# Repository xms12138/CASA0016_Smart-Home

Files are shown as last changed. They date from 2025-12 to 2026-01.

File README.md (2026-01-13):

# 🏡 HomeCare Assist  

**Smart-Home Prototype for Elderly Comfort & Safety**  

A lightweight Arduino-based system for indoor comfort monitoring and automated actuation.

---

## ✨ Overview  

**HomeCare Assist** is a room-level smart prototype designed to support **elderly individuals living alone**, helping them maintain a safer and more comfortable indoor environment—**without cameras, wearables, or user intervention**.

The system continuously monitors:

- Indoor **CO₂ / temperature / humidity**
- Indoor & outdoor **light levels**
- **Thermal-based occupancy** 
- Potential **fire hazards**

And automatically:

- Opens/closes curtains based on natural light
- Activates ventilation when air quality/temperature rises
- Triggers alarms when fire is detected
- Publishes live data via **MQTT** for remote monitoring & manual control

<p align="center">
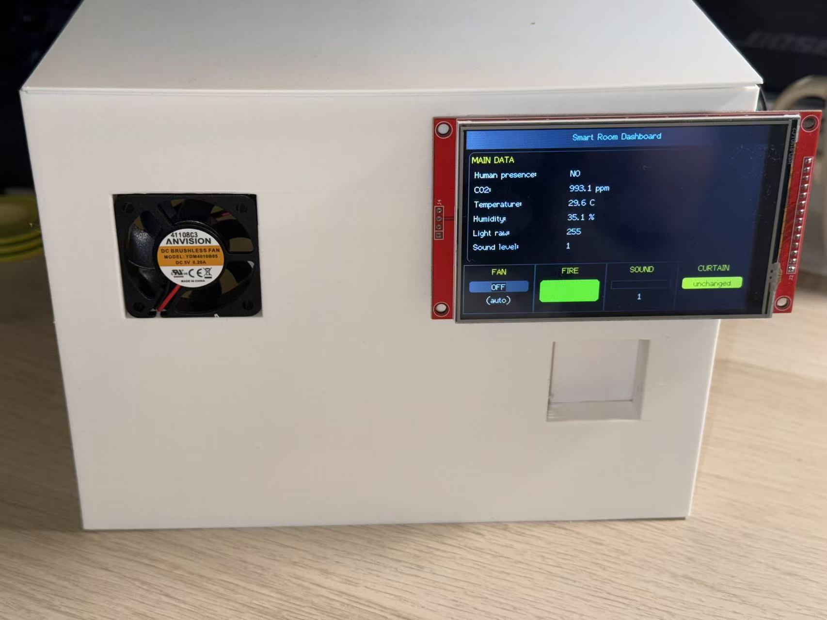
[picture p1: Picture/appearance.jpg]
  
  <br>
  <strong>Figure 1.</strong> Physical Prototype Overview
</p>

---

## 🧩 Key Features  

- ✅ Privacy-friendly **thermal presence detection** (no camera)
- ✅ Real-time **multi-sensor monitoring**
- ✅ **Automatic ventilation & curtain control**
- ✅ **MQTT remote supervision + manual override**
- ✅ Local **TFT dashboard UI**
- ✅ Low-power design (suitable for standalone power bank)

------

## 🚀 Installation & Usage

### 1️⃣ Clone

```
git clone https://github.com/xms12138/CASA0016_Smart-Home.git
```

**The complete code of this system is located in the [Final](https://github.com/xms12138/CASA0016_Smart-Home/tree/main/Code/Final). If you just want to give it a try, all you need to do is run this code.**

**Individual debugging sketches for each component are available in the [Components_Test](https://github.com/xms12138/CASA0016_Smart-Home/tree/main/Code/Components_Test) folder and can be run independently if required.**

### 2️⃣ Arduino Libraries

Install these in Arduino IDE:

- Adafruit MLX90640
- Adafruit SCD30
- TFT_eSPI
- WiFiNINA
- PubSubClient
- Servo

### 3️⃣ Configure WiFi + MQTT

Edit in your Arduino sketch:

```
char ssid[] = "YOUR_WIFI";
char pass[] = "YOUR_PASSWORD";

const char* mqttServer = "Your_Server";
const int mqttPort = "Your_Port";
```

### 4️⃣ Upload & Run

- Wire all sensors following the schematic
- Upload sketch to **Arduino MKR WiFi 1010**
- Verify TFT screen updates
- Use an MQTT client (e.g. EasyMQTT) to publish fan commands

------

## 📂 Recommended Repository Structure

```
CASA0016_Smart-Home/
│
├── 3D-Printer/    – 3D model files for the device enclosure and printed parts
│
├── Code/          – Arduino firmware and source code for sensors, actuators and MQTT
│
├── Picture/       – Photos, wiring images, UI screenshots and documentation images
│
└── website/       – Web dashboard (HTML/CSS/JS) for visualizing device data

```

Each folder corresponds to a core part of the smart home prototype:

- **3D-Printer** → physical housing & printed components
- **Code** → main hardware logic running on the microcontroller
- **Picture** → project images and build documentation
- **website** → the browser-based dashboard for monitoring

---

## 🛠 Hardware Used  

| Component | Purpose |
| --- | --- |
| Arduino MKR WiFi 1010 | Main controller, WiFi connectivity |
| MLX90640 (32×24 Thermal Camera) | Human presence detection |
| SCD30 | CO₂ + Temperature + Humidity monitoring |
| Light sensor (LDR) | Ambient light measurement |
| Flame sensor | Fire detection |
| MG90S Servo | Simulated curtain control |
| 5V Fan | Auto / remote ventilation |
| TFT_eSPI Display (480×320) | On-device dashboard UI |

---

## 🧱 System Architecture  

The system runs on an Arduino MKR WiFi 1010 and integrates five key modules:

 MLX90640 for thermal presence detection, SCD30 for CO₂/temperature/humidity, an LDR for light sensing, a flame sensor for fire detection, and actuators including a PWM-controlled fan and a servo-driven curtain. All readings are displayed locally on a TFT screen and trigger automatic responses. The circuit diagram is as follows:

<p align="center">
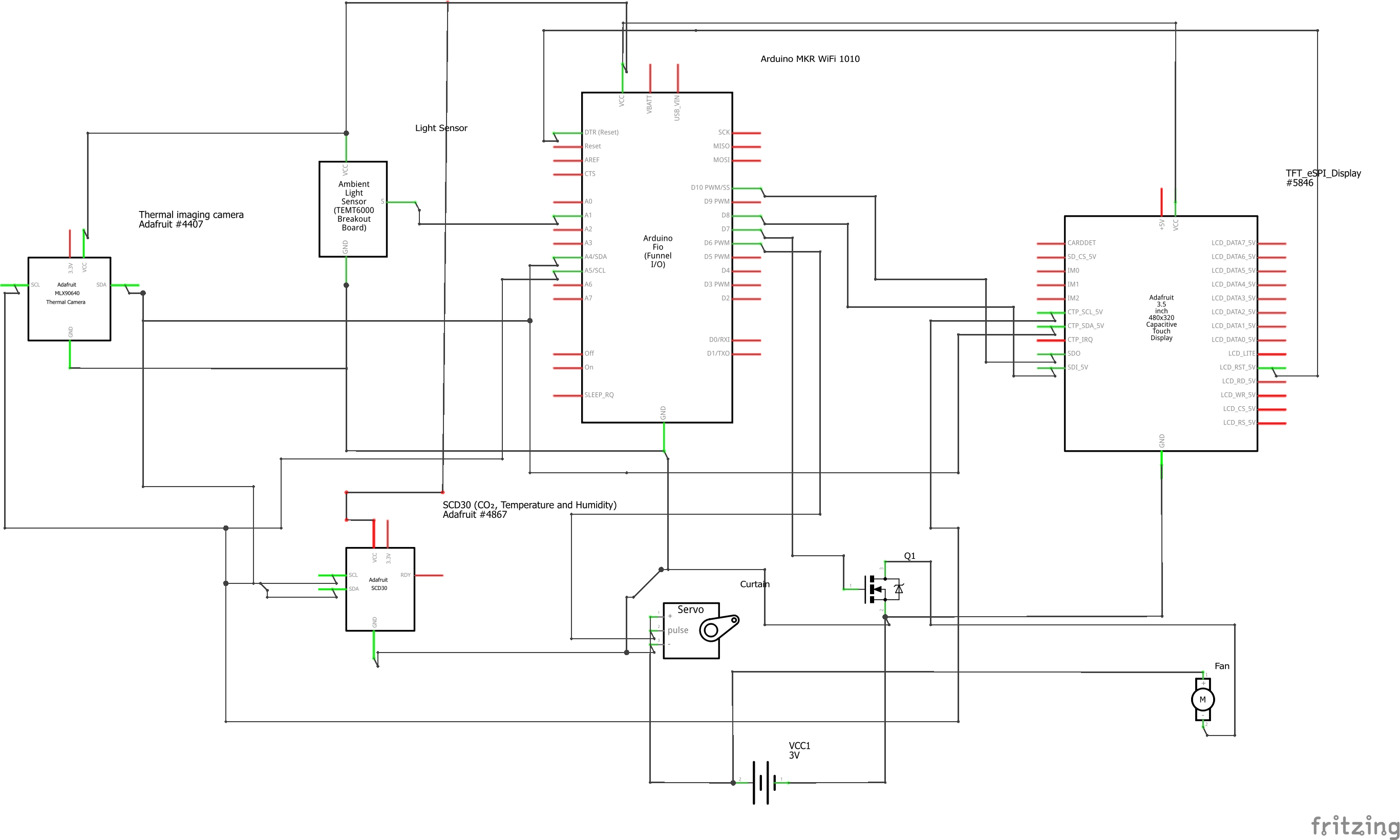
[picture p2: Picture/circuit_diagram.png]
  
  <br>
  <strong>Figure 2.</strong> Circuit Diagram
</p>

The component diagram is as follows:

<p align="center">
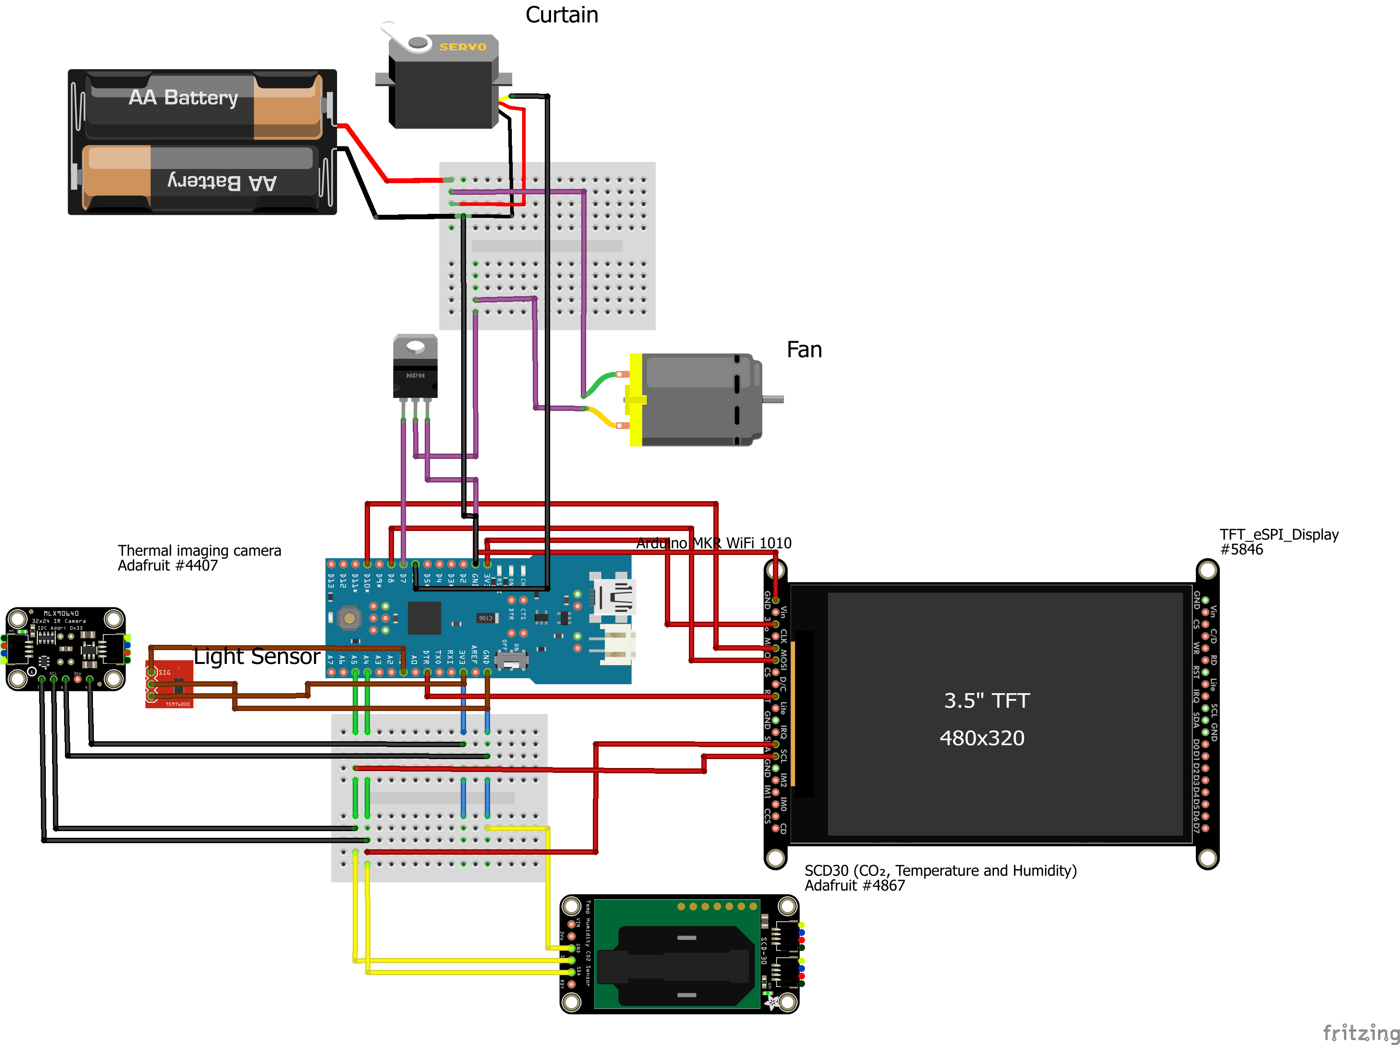
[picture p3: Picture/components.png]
  
  <br>
  <strong>Figure 3.</strong> Components Diagram
</p>

------

## 🧪 Software Logic and Core Function

The system first determines occupancy using the thermal imager. If empty, all actuators stay idle. When occupied, rule-based thresholds control devices: CO₂ and temperature trigger the fan, light opens the curtains, and a flame event raises an alarm. This ensures predictable behaviour across all sensors. The workflow diagram is as follows:

<p align="center">
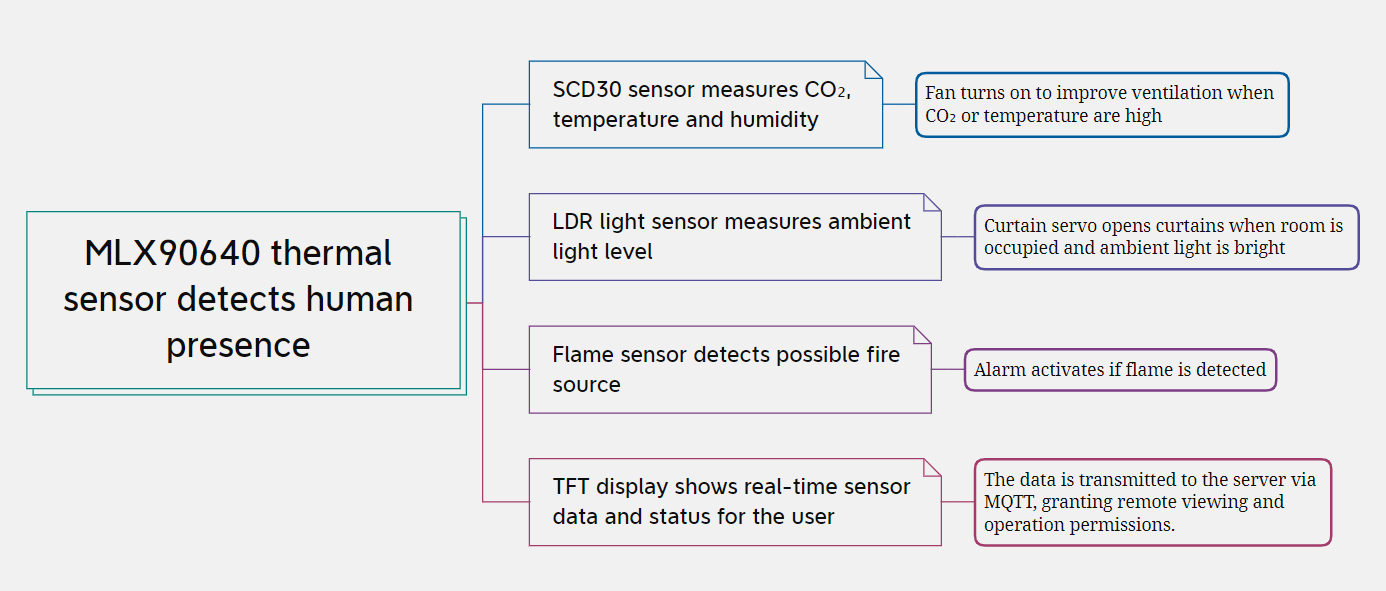
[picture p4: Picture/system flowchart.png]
  
  <br>
  <strong>Figure 4.</strong> System Flowchart
</p>

### 🔥 Thermal Presence Detection (MLX90640)

Presence is inferred using an adaptive, statistics-based method rather than fixed thresholds:

- Compute global mean **μ** and standard deviation **σ** per 32×24 frame
- Mark “hot” pixels by **z-score thresholding**
- Aggregate into **8×6 blocks** to suppress isolated noise
- Require global contrast check (**Tmax − μ**)
- Apply **temporal smoothing** to stabilize decisions

<p align="center">
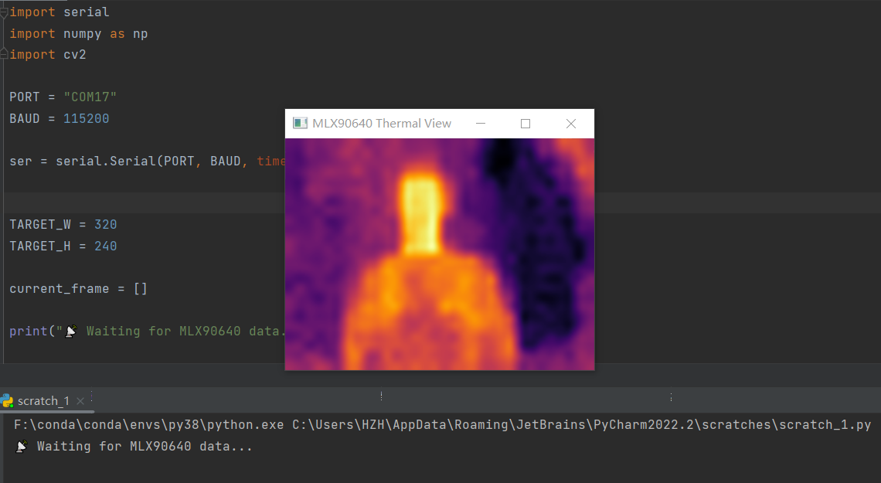
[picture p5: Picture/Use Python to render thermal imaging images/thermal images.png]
  
  <br>
  <strong>Figure 5.</strong> Use Python to render thermal imaging images
</p>

------

### 🌬 Automatic & Remote Fan Control

Automatic mode runs only when presence is detected:

- Fan ON if **CO₂ > 5000 ppm** OR **Temperature > 29°C**
- MQTT remote control can force ON/OFF using:
  - Topic: `student/MUJI/HZH/command/fan`
  - Payload: `"on"` / `"off"`

<p align="center">
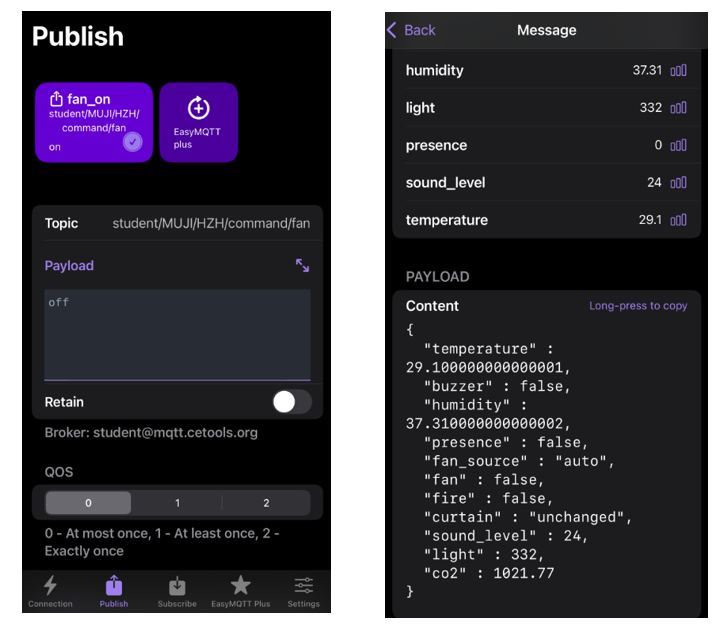
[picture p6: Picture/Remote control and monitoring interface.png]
  
  <br>
  <strong>Figure 6.</strong> Remote control and monitoring interface
</p>

Example JSON payload (remote monitoring):

```
{
  "temperature": 29.1,
  "humidity": 37.3,
  "presence": false,
  "fan_source": "auto",
  "fan": false,
  "fire": false,
  "curtain": "unchanged",
  "light": 332,
  "co2": 1021.8
}

```

------

### 🖥 Local TFT Dashboard + Website page

The local TFT UI shows:

- Presence status
- CO₂ ppm
- Temperature & Humidity
- Light level
- Status bar for **Fan / Fire / Sound / Curtain**

<p align="center">
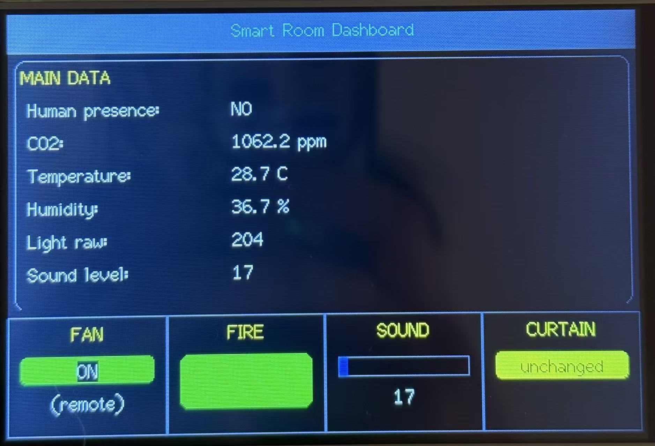
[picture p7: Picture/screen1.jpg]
  
  <br>
  <strong>Figure 7.</strong> TFT Dashboard
</p>

<p align="center">
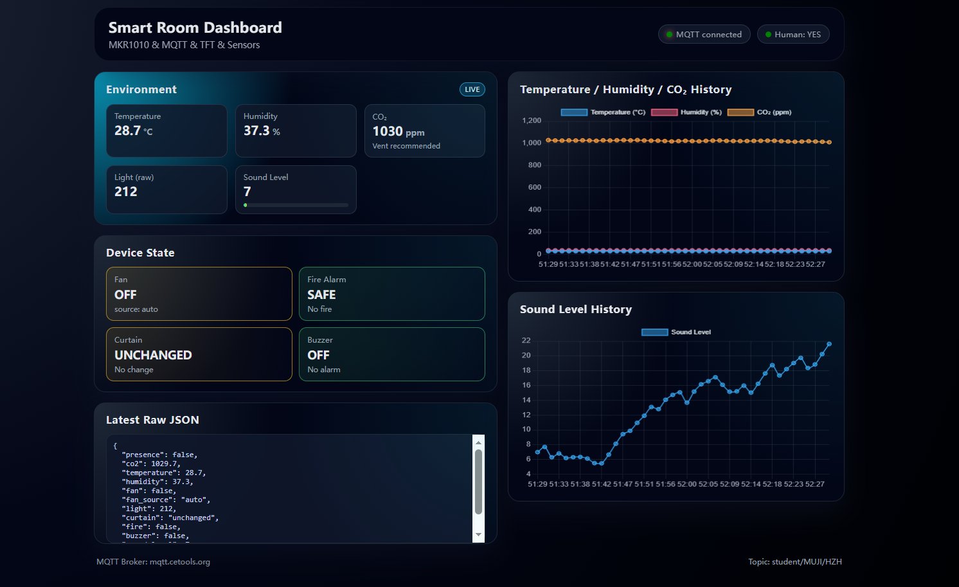
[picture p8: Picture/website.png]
  
  <br>
  <strong>Figure 8.</strong> Website Page
</p>

------

## 📊 Evaluation Summary

- Prototype achieved core objectives: sensing + control + MQTT monitoring
- Low-power test: **20,000 milliampere power bank powered system for > 1 week**
- All modules worked reliably in development environment

------

## 🔧 Limitations & Future Work

Limitations observed:

- Thermal detection can be affected by background heat sources and ambient temperature similarity
- Thresholds are coarse and not universal across rooms/seasons
- Too many modules reduce robustness (wiring looseness causes failures)

Future improvements:

- Simplify sensing setup (reduce redundant hardware)
- Replace fixed thresholds with adaptive logic
- Collect data for lightweight ML-based decision rules

------

## 📄 License  

This project is released under the MIT License.

------

## 📄References

Bouazizi, M., Ye, C. and Ohtsuki, T. (2022) ‘Low-resolution infrared array sensor for counting and localizing people indoors: When low end technology meets cutting edge deep learning techniques’, *Information*, 13(3), 132. doi:10.3390/info13030132.

 Du, B. et al. (2020) ‘Indoor CO₂ concentrations and cognitive function: A critical review’, *Indoor Air*, 30(6), pp. 1005–1016. Available at: [https://pubmed.ncbi.nlm.nih.gov/32557862/](https://pubmed.ncbi.nlm.nih.gov/32557862/?utm_source=chatgpt.com)

 Fan, Y. et al. (2023) ‘Short-term exposure to indoor carbon dioxide and human cognitive performance’, *Building and Environment*, 243, 110682. Available at: [https://www.sciencedirect.com/science/article/pii/S036013232300358X](https://www.sciencedirect.com/science/article/pii/S036013232300358X?utm_source=chatgpt.com)

 Lin, Y. and Zhao, Q. (2025) ‘Human occupancy monitoring and positioning with speed-responsive adaptive sliding window using an infrared thermal array sensor’, *Sensors*, 25(1), 129. doi:10.3390/s25010129.

 Jo, T.H., Ma, J.H. and Cha, S.H. (2021) ‘Elderly perception on the Internet of Things-based integrated smart-home system’, *Sensors*, 21(4), 1284. Available at: [https://www.mdpi.com/1424-8220/21/4/1284](https://www.mdpi.com/1424-8220/21/4/1284?utm_source=chatgpt.com)

 Wang, Y., Zhang, X., Zhang, Y. and Wang, K. (2021) ‘Multisensor fusion in smart buildings: A review’, *Automation in Construction*, 125, 103600. Available at: https://www.sciencedirect.com/science/article/pii/S0926580521001791

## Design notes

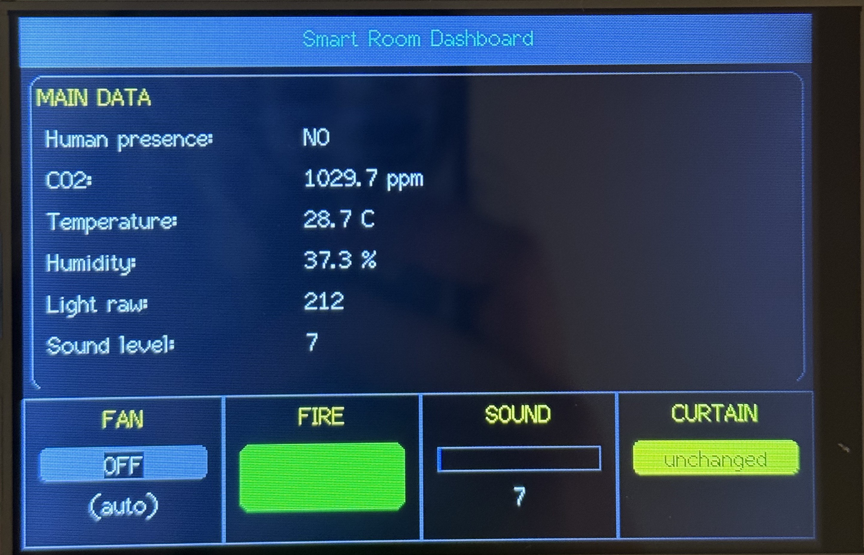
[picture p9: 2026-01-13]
Picture/screen.jpg

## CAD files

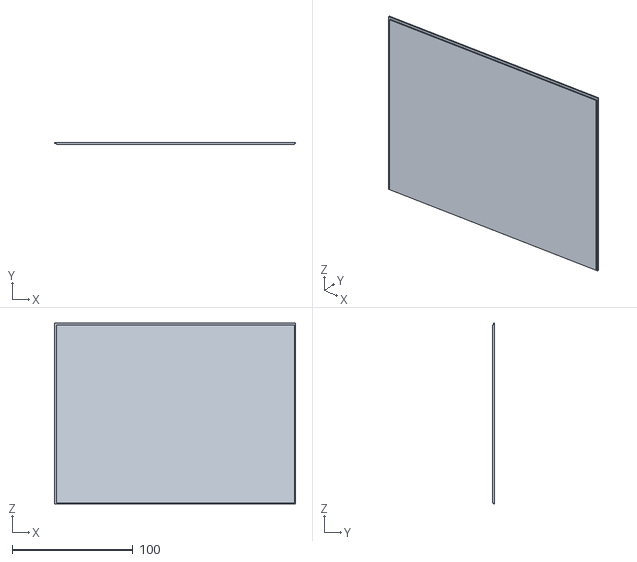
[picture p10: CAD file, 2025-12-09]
3D-Printer/cover.stl
200.0 x 2.00 x 150.0

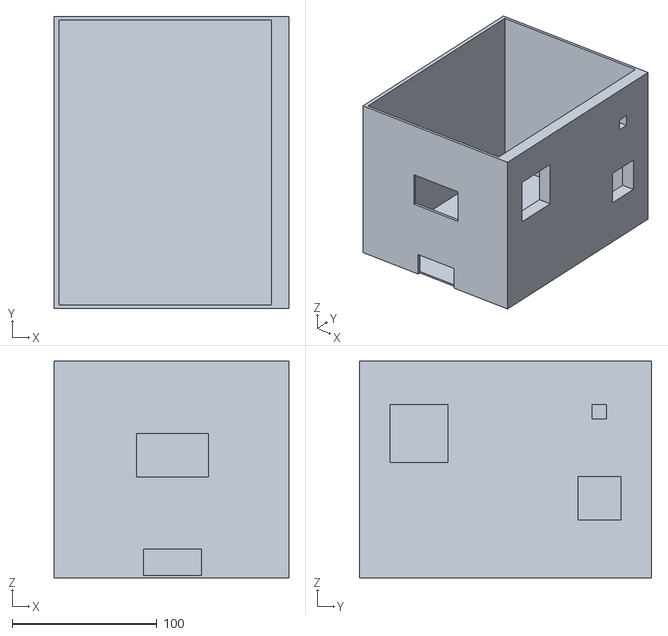
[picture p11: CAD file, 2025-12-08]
3D-Printer/house.stl
162.5 x 202.0 x 150.0

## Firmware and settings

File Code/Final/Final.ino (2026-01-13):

#include <Wire.h>
#include <Adafruit_MLX90640.h>
#include <Adafruit_SCD30.h>
#include <Servo.h>
#include <WiFiNINA.h>
#include <PubSubClient.h>
#include <TFT_eSPI.h>
#include <SPI.h>

char ssid[] = "";
char pass[] = "";


const char* mqttServer = "mqtt.cetools.org";
const int mqttPort = 1884;
const char* mqttUser = "student";
const char* mqttPass = "ce2021-mqtt-forget-whale";
const char* mqttTopic = "student/MUJI/HZH";
const char* mqttCmdFanTopic = "student/MUJI/HZH/command/fan";

WiFiClient wifiClient;
PubSubClient mqttClient(wifiClient);

TFT_eSPI tft = TFT_eSPI();

#define COLOR_TITLE   TFT_CYAN
#define COLOR_VALUE   TFT_WHITE
#define COLOR_SECTION TFT_YELLOW
#define COLOR_LINE    TFT_DARKGREY

Adafruit_MLX90640 mlx;
Adafruit_SCD30   scd30;
Servo            curtainServo;

float frame[32 * 24];          // 768 pixels (24x32)

// ----------- Advanced presence detection parameters (tunable) -----------
const float Z_THRESHOLD          = 2.3f;   // z-score threshold: higher = more conservative
const float MIN_GLOBAL_DELTA     = 3.0f;   // (maxT - mean) minimum difference required
const int   MIN_PIXELS_PER_BLOCK = 2;      // minimum hot pixels within each 4x4 block
const int   MIN_HOT_BLOCKS       = 3;      // minimum number of blocks meeting criteria
// Temporal smoothing
const int   MAX_SCORE            = 6;      // upper bound on stability score
const int   STABLE_SCORE         = 3;      // threshold above which presence is confirmed
// -----------------------------------------------------------------------

int presenceScore = 0;           // score accumulator for temporal smoothing

// Image size and block partitioning
const int IMG_W = 32;
const int IMG_H = 24;
const int BLOCK_W = 8;
const int BLOCK_H = 6;
const int BLOCK_SIZE_X = IMG_W / BLOCK_W;  // 4 pixels per block (horizontal)
const int BLOCK_SIZE_Y = IMG_H / BLOCK_H;  // 4 pixels per block (vertical)

// Single-frame advanced human detection
bool detectHumanFrame(const float *f) {
  // 1. Compute mean, standard deviation, and max temperature
  float sum  = 0.0f;
  float var  = 0.0f;
  float maxT = -1000.0f;

  for (int i = 0; i < IMG_W * IMG_H; i++) {
    float t = f[i];
    sum += t;
    if (t > maxT) maxT = t;
  }

  float mean = sum / (IMG_W * IMG_H);

  // Compute variance
  for (int i = 0; i < IMG_W * IMG_H; i++) {
    float diff = f[i] - mean;
    var += diff * diff;
  }

  float stdDev = sqrtf(var / (IMG_W * IMG_H) + 1e-6f);

  // 2. Mark candidate "hot pixels" based on z-score
  static uint8_t hotMask[IMG_W * IMG_H];  // 768 bytes OK for MKR1010
  int totalHotPixels = 0;

  for (int i = 0; i < IMG_W * IMG_H; i++) {
    float z = (f[i] - mean) / stdDev;
    if (z > Z_THRESHOLD) {
      hotMask[i] = 1;
      totalHotPixels++;
    } else {
      hotMask[i] = 0;
    }
  }

  // 3. Spatial clustering using 4x4 blocks
  int hotBlocks = 0;

  for (int by = 0; by < BLOCK_H; by++) {
    for (int bx = 0; bx < BLOCK_W; bx++) {
      int blockHot = 0;

      // Iterate through all pixels in a block
      for (int dy = 0; dy < BLOCK_SIZE_Y; dy++) {
        for (int dx = 0; dx < BLOCK_SIZE_X; dx++) {
          int x = bx * BLOCK_SIZE_X + dx;
          int y = by * BLOCK_SIZE_Y + dy;
          int idx = y * IMG_W + x;
          if (hotMask[idx]) {
            blockHot++;
          }
        }
      }

      if (blockHot >= MIN_PIXELS_PER_BLOCK) {
        hotBlocks++;
      }
    }
  }

  // 4. Global sanity check: prevents false positives when entire room warms evenly
  bool framePresence = (hotBlocks >= MIN_HOT_BLOCKS) &&
                       ((maxT - mean) > MIN_GLOBAL_DELTA);

  // Debug output
  Serial.print("mean=");
  Serial.print(mean, 2);
  Serial.print(" max=");
  Serial.print(maxT, 2);
  Serial.print(" hotPixels=");
  Serial.print(totalHotPixels);
  Serial.print(" hotBlocks=");
  Serial.print(hotBlocks);
  Serial.print(" framePresence=");
  Serial.println(framePresence ? "YES" : "NO");

  return framePresence;
}

// Multi-frame temporal smoothing + final decision
bool updatePresence() {
  int status = mlx.getFrame(frame);
  if (status != 0) {
    Serial.print("getFrame error: ");
    Serial.println(status);
    return false;
  }

  bool framePresence = detectHumanFrame(frame);

  // Smoothing: ramp score up/down based on consecutive detections
  if (framePresence) {
    if (presenceScore < MAX_SCORE) presenceScore++;
  } else {
    if (presenceScore > 0) presenceScore--;
  }

  bool presence = (presenceScore >= STABLE_SCORE);

  Serial.print("presenceScore=");
  Serial.print(presenceScore);
  Serial.print(" -> presence=");
  Serial.println(presence ? "YES" : "NO");

  return presence;
}

// ------------------------- Other device config -------------------------

const int FAN_PIN   = 7;
const int LIGHT_PIN = A1;
const int LIGHT_THRESHOLD = 600;
const int SERVO_PIN = 6;
const int FLAME_PIN = 2;
const int BUZZER_PIN = 5;

float latestCO2 = NAN;
bool hasCO2 = false;

int  currentServoAngle = -1;

bool         buzzerOn = false;
unsigned long buzzerStartMillis = 0;
bool         lastFireDetected = false;

int remoteFanMode = -1;

const int SOUND_PIN = A2;
float baselineAlpha = 0.98;
float soundAlpha    = 0.85;
float baseline      = 0;
int   soundLevel    = 0;

unsigned long lastSampleTime      = 0;
const int     SAMPLE_INTERVAL_MS  = 100;

// ------------------------- Utility functions ---------------------------

int readFastAverage(int samples = 20) {
  long s = 0;
  for (int i = 0; i < samples; i++) {
    s += analogRead(SOUND_PIN);
    delay(2);
  }
  return (int)(s / samples);
}

void drawBaseLayout() {
  tft.fillScreen(TFT_BLACK);
  tft.fillRect(0, 0, 480, 30, TFT_DARKGREY);
  tft.setTextColor(COLOR_TITLE, TFT_DARKGREY);
  tft.drawCentreString("Smart Room Dashboard", 240, 5, 2);

  tft.drawRoundRect(5, 35, 470, 190, 8, COLOR_LINE);
  tft.setTextColor(COLOR_SECTION, TFT_BLACK);
  tft.drawString("MAIN DATA", 10, 40, 2);

  int cellW = 480 / 4;
  tft.drawRect(0,        230, cellW, 90, COLOR_LINE);
  tft.drawRect(cellW,    230, cellW, 90, COLOR_LINE);
  tft.drawRect(cellW * 2,230, cellW, 90, COLOR_LINE);
  tft.drawRect(cellW * 3,230, cellW, 90, COLOR_LINE);

  tft.setTextColor(COLOR_SECTION, TFT_BLACK);
  tft.drawCentreString("FAN",     cellW / 2,          235, 2);
  tft.drawCentreString("FIRE",    cellW + cellW / 2,  235, 2);
  tft.drawCentreString("SOUND",   cellW * 2 + cellW / 2, 235, 2);
  tft.drawCentreString("CURTAIN", cellW * 3 + cellW / 2, 235, 2);
}

void updateMainDataPanel(bool human, bool hasCO2, float co2, float temp,
                         float humidity, int lightRaw, int soundLevel) {
  int xLabel = 15;
  int xValue = 170;
  int yStart = 65;
  int lineH  = 25;

  tft.fillRect(10, 60, 460, 165, TFT_BLACK);
  tft.setTextColor(COLOR_VALUE, TFT_BLACK);

  tft.drawString("Human presence:", xLabel, yStart, 2);
  tft.drawString(human ? "YES" : "NO", xValue, yStart, 2);

  if (hasCO2) {
    tft.drawString("CO2:", xLabel, yStart + lineH, 2);
    tft.drawString(String(co2, 1) + " ppm", xValue, yStart + lineH, 2);

    tft.drawString("Temperature:", xLabel, yStart + lineH * 2, 2);
    tft.drawString(String(temp, 1) + " C", xValue, yStart + lineH * 2, 2);

    tft.drawString("Humidity:", xLabel, yStart + lineH * 3, 2);
    tft.drawString(String(humidity, 1) + " %", xValue, yStart + lineH * 3, 2);
  } else {
    tft.drawString("CO2 / Temp / Hum:", xLabel, yStart + lineH, 2);
    tft.drawString("Waiting SCD30 data...", xValue, yStart + lineH, 2);
  }

  tft.drawString("Light raw:", xLabel, yStart + lineH * 4, 2);
  tft.drawString(String(lightRaw), xValue, yStart + lineH * 4, 2);

  tft.drawString("Sound level:", xLabel, yStart + lineH * 5, 2);
  tft.drawString(String(soundLevel), xValue, yStart + lineH * 5, 2);
}

void drawFanStatus(bool fanOn, const String &fanSource) {
  int cellW = 480 / 4;
  int x = 0;
  int y = 255;
  int w = cellW;
  int h = 60;

  tft.fillRect(x + 2, y, w - 4, h, TFT_BLACK);

  uint16_t color = fanOn ? TFT_GREEN : TFT_DARKGREY;
  tft.fillRoundRect(x + 10, y + 5, w - 20, 20, 4, color);

  tft.setTextColor(COLOR_VALUE, TFT_BLACK);
  tft.drawCentreString(fanOn ? "ON" : "OFF", x + w / 2, y + 8, 2);
  tft.drawCentreString("(" + fanSource + ")", x + w / 2, y + 32, 2);
}

void drawFireStatus(bool fireDetected) {
  int cellW = 480 / 4;
  int x = cellW;
  int y = 255;
  int w = cellW;
  int h = 60;

  tft.fillRect(x + 2, y, w - 4, h, TFT_BLACK);

  if (fireDetected) {
    tft.fillRoundRect(x + 10, y + 5, w - 20, 40, 6, TFT_RED);
    tft.setTextColor(TFT_WHITE, TFT_RED);
    tft.drawCentreString("FIRE!", x + w / 2, y + 16, 4);
  } else {
    tft.fillRoundRect(x + 10, y + 5, w - 20, 40, 6, TFT_GREEN);
    tft.setTextColor(TFT_BLACK, TFT_GREEN);
    tft.drawCentreString("SAFE", x + w / 2, y + 16, 4);
  }
}

void drawSoundStatus(int soundLevel) {
  int cellW = 480 / 4;
  int x = cellW * 2;
  int y = 255;
  int w = cellW;
  int h = 60;

  tft.fillRect(x + 2, y, w - 4, h, TFT_BLACK);

  int maxVal = 200;
  int levelClamped = soundLevel;
  if (levelClamped < 0) levelClamped = 0;
  if (levelClamped > maxVal) levelClamped = maxVal;

  int barW = (int)((float)levelClamped / maxVal * (w - 20));

  tft.drawRect(x + 10, y + 8, w - 20, 15, COLOR_LINE);
  tft.fillRect(x + 11, y + 9, barW - 2 < 0 ? 0 : barW - 2, 13, TFT_BLUE);

  tft.setTextColor(COLOR_VALUE, TFT_BLACK);
  tft.drawCentreString(String(levelClamped), x + w / 2, y + 30, 2);
}

void drawCurtainStatus(const String &curtainState) {
  int cellW = 480 / 4;
  int x = cellW * 3;
  int y = 255;
  int w = cellW;
  int h = 60;

  tft.fillRect(x + 2, y, w - 4, h, TFT_BLACK);

  uint16_t color;
  if (curtainState == "open")      color = TFT_CYAN;
  else if (curtainState == "close")color = TFT_DARKGREY;
  else                             color = TFT_YELLOW;

  tft.fillRoundRect(x + 10, y + 5, w - 20, 20, 4, color);
  tft.setTextColor(TFT_BLACK, color);
  tft.drawCentreString(curtainState, x + w / 2, y + 8, 2);
}

// ------------------------- MQTT & WiFi --------------------------

void mqttCallback(char* topic, byte* payload, unsigned int length) {
  String t = String(topic);
  String msg;
  for (unsigned int i = 0; i < length; i++) {
    msg += (char)payload[i];
  }
  msg.trim();

  Serial.print("MQTT cmd topic = ");
  Serial.print(t);
  Serial.print("  payload = ");
  Serial.println(msg);

  if (t == String(mqttCmdFanTopic)) {
    if (msg.equalsIgnoreCase("on"))      remoteFanMode = 1;
    else if (msg.equalsIgnoreCase("off"))remoteFanMode = 0;
  }
}

void connectWiFi() {
  Serial.print("Connecting to WiFi...");
  while (WiFi.begin(ssid, pass) != WL_CONNECTED) {
    Serial.print(".");
    delay(1000);
  }
  Serial.println(" connected!");
}

void connectMQTT() {
  mqttClient.setServer(mqttServer, mqttPort);

  while (!mqttClient.connected()) {
    Serial.print("Connecting to MQTT...");
    if (mqttClient.connect("MKR1010_client", mqttUser, mqttPass)) {
      Serial.println(" connected!");
      mqttClient.subscribe(mqttCmdFanTopic);
      Serial.print("Subscribed to: ");
      Serial.println(mqttCmdFanTopic);
    } else {
      Serial.print(" failed, rc=");
      Serial.println(mqttClient.state());
      delay(2000);
    }
  }
}

// ----------------------------- setup ----------------------------

void setup() {
  Serial.begin(115200);
  delay(2000);

  connectWiFi();
  mqttClient.setCallback(mqttCallback);
  connectMQTT();

  Serial.println("MLX90640 + SCD30 + Fan + Light + Servo + Flame + Buzzer + SoundLevel + MQTT + TFT (MKR1010)");

  tft.init();
  tft.setRotation(1);
  drawBaseLayout();

  Wire.begin();
  Wire.setClock(400000);

  if (!mlx.begin(0x33, &Wire)) {
    Serial.println("MLX90640 not found!");
    while (1);
  }

  mlx.setMode(MLX90640_INTERLEAVED);
  mlx.setResolution(MLX90640_ADC_18BIT);
  mlx.setRefreshRate(MLX90640_4_HZ);

  scd30.begin();

  pinMode(FAN_PIN,   OUTPUT);
  pinMode(LIGHT_PIN, INPUT);
  pinMode(FLAME_PIN, INPUT);
  pinMode(BUZZER_PIN, OUTPUT);
  noTone(BUZZER_PIN);
  pinMode(SOUND_PIN, INPUT);

  curtainServo.attach(SERVO_PIN, 500, 2500);
  currentServoAngle = -1;

  baseline = readFastAverage(50);
  soundLevel = 0;
  lastSampleTime = millis();
}

// ----------------------------- loop -----------------------------

void loop() {
  if (!mqttClient.connected()) connectMQTT();
  mqttClient.loop();

  unsigned long now = millis();
  if (now - lastSampleTime >= SAMPLE_INTERVAL_MS) {
    lastSampleTime = now;

    int current = readFastAverage(15);
    baseline = baselineAlpha * baseline + (1.0 - baselineAlpha) * current;
    int level = current - (int)baseline;
    if (level < 0) level = 0;

    soundLevel = (int)(soundAlpha * soundLevel + (1.0 - soundAlpha) * level);

    Serial.print("Sound level = ");
    Serial.println(soundLevel);
  }

  // ---- Advanced human presence detection (uses MLX + frame internally) ----
  bool human = updatePresence();

  // ---- SCD30 CO2 / Temp / Humidity ----
  if (scd30.dataReady()) {
    scd30.read();
    latestCO2 = scd30.CO2;
    hasCO2 = true;
  }

  if (hasCO2) {
    Serial.print("CO2 = ");         Serial.println(latestCO2);
    Serial.print("Temperature = "); Serial.println(scd30.temperature);
    Serial.print("Humidity = ");    Serial.println(scd30.relative_humidity);
  }

  // ---- Fan logic (CO2 / temp driven, with remote override when no human) ----
  bool   fanOn    = false;
  String fanSource = "auto";

  if (human) {
    // Local presence: ignore remote override
    remoteFanMode = -1;
    if (hasCO2 && (latestCO2 > 5000.0 || scd30.temperature > 29.0)) {
      fanOn = true;
    }
  } else {
    // No human detected: remote override allowed
    if (remoteFanMode == 1) {
      fanOn    = true;
      fanSource = "remote";
    } else if (remoteFanMode == 0) {
      fanOn    = false;
      fanSource = "remote";
    }
  }

  digitalWrite(FAN_PIN, fanOn ? HIGH : LOW);
  Serial.print("Fan state: ");
  Serial.print(fanOn ? "ON" : "OFF");
  Serial.print("  source=");
  Serial.println(fanSource);

  // ---- Light + curtain control ----
  int lightRaw = analogRead(LIGHT_PIN);
  Serial.print("Light raw = "); Serial.println(lightRaw);

  String curtainState = "";

  if (human) {
    if (lightRaw > LIGHT_THRESHOLD) {
      curtainState = "open";
      if (currentServoAngle != 180) {
        curtainServo.write(180);
        currentServoAngle = 180;
        Serial.println("Curtain: OPEN");
      }
    } else {
      curtainState = "close";
      if (currentServoAngle != 0) {
        curtainServo.write(0);
        currentServoAngle = 0;
        Serial.println("Curtain: CLOSE");
      }
    }
  } else {
    curtainState = "unchanged";
  }

  // ---- Flame sensor + buzzer ----
  bool fireDetected = (digitalRead(FLAME_PIN) == HIGH);
  Serial.print("Fire: "); Serial.println(fireDetected ? "YES" : "NO");

  if (fireDetected && !lastFireDetected) {
    buzzerOn = true;
    buzzerStartMillis = millis();
    tone(BUZZER_PIN, 4000);
  }

  if (buzzerOn && (millis() - buzzerStartMillis >= 5000)) {
    buzzerOn = false;
    noTone(BUZZER_PIN);
  }

  lastFireDetected = fireDetected;

  // ---- TFT UI update ----
  updateMainDataPanel(human,
                      hasCO2,
                      latestCO2,
                      scd30.temperature,
                      scd30.relative_humidity,
                      lightRaw,
                      soundLevel);

  drawFanStatus(fanOn, fanSource);
  drawFireStatus(fireDetected);
  drawSoundStatus(soundLevel);
  drawCurtainStatus(curtainState);

  // ---- MQTT JSON payload ----
  String payload = "{";
  payload += "\"presence\":"     + String(human ? "true" : "false") + ",";
  payload += "\"co2\":"          + String(latestCO2, 2) + ",";
  payload += "\"temperature\":"  + String(scd30.temperature, 2) + ",";
  payload += "\"humidity\":"     + String(scd30.relative_humidity, 2) + ",";
  payload += "\"fan\":"          + String(fanOn ? "true" : "false") + ",";
  payload += "\"fan_source\":\"" + fanSource + "\",";
  payload += "\"light\":"        + String(lightRaw) + ",";
  payload += "\"curtain\":\""    + curtainState + "\",";
  payload += "\"fire\":"         + String(fireDetected ? "true" : "false") + ",";
  payload += "\"buzzer\":"       + String(buzzerOn ? "true" : "false") + ",";
  payload += "\"sound_level\":"  + String(soundLevel);
  payload += "}";

  mqttClient.publish(mqttTopic, payload.c_str());
  Serial.println("MQTT Sent:");
  Serial.println(payload);

  delay(250);  // roughly matches MLX 4 FPS
}

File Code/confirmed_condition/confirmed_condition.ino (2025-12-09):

#include <Wire.h>
#include <Adafruit_MLX90640.h>

Adafruit_MLX90640 mlx;
float frame[32 * 24];   // 768 个像素

// ----------- 人体检测参数，可以之后微调 -----------
const float TEMP_DELTA_THRESHOLD = 3.5;  // 阈值：高于平均温度多少度算“热”
const int   MIN_HOT_PIXELS       = 8;    // 至少多少个“热像素”才算有人
// -------------------------------------------------

// 检测当前帧是否有人
bool detectHuman(const float *f) {
  float sum = 0.0;
  float minT = 1000.0;
  float maxT = -1000.0;

  // 先遍历一遍，求平均 / 最小 / 最大温度
  for (int i = 0; i < 32 * 24; i++) {
    float t = f[i];
    sum += t;
    if (t < minT) minT = t;
    if (t > maxT) maxT = t;
  }

  float avg = sum / (32.0 * 24.0);       // 平均温度
  float threshold = avg + TEMP_DELTA_THRESHOLD;

  // 再遍历一遍，统计高于阈值的像素
  int hotPixels = 0;
  for (int i = 0; i < 32 * 24; i++) {
    if (f[i] > threshold) {
      hotPixels++;
    }
  }

  bool presence = (hotPixels >= MIN_HOT_PIXELS) &&
                  ((maxT - avg) > TEMP_DELTA_THRESHOLD);

  // 为了调试，打印一些信息
  Serial.print("avg=");
  Serial.print(avg, 2);
  Serial.print("  max=");
  Serial.print(maxT, 2);
  Serial.print("  hotPixels=");
  Serial.print(hotPixels);
  Serial.print("  presence=");
  Serial.println(presence ? "YES" : "NO");

  return presence;
}

void setup() {
  Serial.begin(115200);
  delay(2000);

  Serial.println("MLX90640 Human Presence Test (MKR1010)");

  Wire.begin();              // MKR1010 默认 SDA/SCL
  Wire.setClock(400000);     // 400kHz I2C

  if (!mlx.begin(0x33, &Wire)) {
    Serial.println("❌ MLX90640 not found! Check wiring.");
    while (1) delay(1000);
  }

  Serial.println("✅ MLX90640 detected!");

  mlx.setMode(MLX90640_INTERLEAVED);
  mlx.setResolution(MLX90640_ADC_18BIT);
  mlx.setRefreshRate(MLX90640_4_HZ);  // 4Hz 刷新
}

void loop() {
  int status = mlx.getFrame(frame);

  if (status != 0) {
    Serial.print("getFrame error: ");
    Serial.println(status);
    return;
  }

  // 调用检测函数
  bool human = detectHuman(frame);

  // 如果你还想保留原来的矩阵输出，可以把下面这段注释打开
  /*
  Serial.println("FRAME_START");
  for (int y = 0; y < 24; y++) {
    for (int x = 0; x < 32; x++) {
      Serial.print(frame[y * 32 + x], 1);
      if (x < 31) Serial.print(", ");
    }
    Serial.println();
  }
  Serial.println("FRAME_END");
  */

  // 稍微等一下，再采下一帧
  delay(250);  // 约 4 帧/秒
}

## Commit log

2025-12-08 update some sensors' test code.md
2025-12-09 update test code.md
    [cover.stl]
2026-01-12 Upload some code and picture
    [fritzing.fzz]
